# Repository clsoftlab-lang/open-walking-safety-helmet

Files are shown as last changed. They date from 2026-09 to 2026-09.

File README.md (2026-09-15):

# Open Walking Safety Helmet

**English** · [한국어](README.ko.md)

> ### *Until the day blind people everywhere can walk like anyone else.*
> 전 세계 시각장애인이 일반인처럼 다닐 수 있는 그날까지.

An open-source helmet that helps blind and low-vision people walk safely.
It feels **head-height obstacles**, finds **stairs and drop-offs**, warns about
**approaching bikes, cars and people**, **reads signs aloud**, recognises **friends' faces**
and sends an **SOS** with your location. It tells you through **vibration on your head** and
**voice**.

Everything is free: firmware, 3D-printable parts, wiring, phone app, documents, **and the
patent.**

**Inventor and project lead:** CLSOFTLAB (씨엘소프트랩), Dr. Lee Il-guk (이일국 박사)
**Patent:** Korean Patent No. 10-2560496, released royalty-free for everyone. See the [Patent Pledge](PATENT_PLEDGE.md).

> [!WARNING]
> **Status: v1.0 reference design, not yet field-validated.** It is an assistive aid, not a
> certified medical device. It **does not replace** a white cane, guide dog or orientation
> and mobility training. Read the [safety guide](docs/en/06-safety.md) before walking with it.

---

## Why a helmet and not glasses?

Sensors can miss things. If a collision happens anyway, **a helmet still protects the head.**
So this project never weakens the helmet:

- Start from a **certified bicycle helmet**. Never 3D-print the shell.
- **Never drill, cut or glue** into the helmet.
- Modules attach with **straps and removable pads** so they break away under impact.
- They sit flat on the shell (curved undersides), stick out at most 35–40 mm (30 mm for small modules) and have rounded edges.

## What it does

| You feel / hear | When |
|---|---|
| Forehead buzz that speeds up, then stays on | Something at **head height** ahead (branch, sign, truck mirror): 2 m → 1.2 m → 0.6 m |
| All three motors, two long buzzes + "Step down ahead" | **Stairs down, curb or platform edge** |
| Left or right side buzzes + "Bicycle approaching from the right" | A person, bike or car **moving towards you** |
| Two gentle buzzes on one side + "Mina is ahead on the left" | An **enrolled friend** is nearby |
| Press ○ | **Reads text** in front of you (signs, labels) |
| Press △ | **Describes the scene**: "2 people ahead, bicycle on the right" |
| Hold □ for 3 s, or fall down | **SOS** countdown, then the phone app shows your location with one-tap call and SMS |
| Three short forehead buzzes every 10 s | **Something is broken.** Don't trust silence. Distance sensors keep working. |

Full haptic language: [User guide](docs/en/05-user-guide.md)

## How it works

```
 Camera (wide) ─► object detection · tracking · time-to-contact ─┐
                  face recognition · text reading (on demand)    │
 LiDAR forward ─► head-height obstacle zones  (works without AI) ─┼─► priority arbiter ─► 3 vibration motors
 LiDAR down    ─► stairs / drop-off / step detector              │                    └► voice (open-ear headset)
 IMU           ─► fall detection                                 │                    └► phone app (BLE): location · SOS
 3 buttons ○△□ ─► read · describe · status / SOS ────────────────┘
 Watchdog: every sensor is monitored, and failures are announced
```

- **Runs offline** on a Raspberry Pi 5, CPU only. No GPU, no cloud.
- **The safety path doesn't depend on AI.** LiDAR warnings keep working if the camera or a neural network fails.
- **Faces never leave the helmet.**

Architecture and every number: [System design specification](docs/en/00-system-design-spec.md)

## Hardware at a glance

Raspberry Pi 5 · Camera Module 3 Wide · 2 × TF-Luna LiDAR · MPU-6050 IMU · 3 coin vibration
motors + ULN2003 · 3 tactile buttons · USB audio + open-ear headset · USB-C power bank in your
pocket · a certified bicycle helmet · 3D-printed PETG/TPU parts.

**No soldering** in the reference build. Every part is printable on a 220 × 220 mm printer.
See the [bill of materials](docs/en/01-bill-of-materials.md) for parts and cost ranges, and the **[buying guide](docs/en/10-buying-guide.md)** for verified purchase links and the most common buying mistakes.

## Repository

| Folder | What | Licence |
|---|---|---|
| [`firmware/`](firmware/) | Python firmware for the helmet (with a PC simulator) | Apache-2.0 |
| [`hardware/`](hardware/) | Parametric OpenSCAD sources, ready-to-print STL, renders, wiring diagram | CERN-OHL-P-2.0 |
| [`app/`](app/) | Phone companion web app (Web Bluetooth): location, SOS, settings | Apache-2.0 |
| [`docs/`](docs/) | Design spec, BOM, wiring, printing, assembly, user guide, safety, tests (English + 한국어) | CC BY 4.0 |
| [`1020210101227.pdf`](1020210101227.pdf) | Original patent publication (Korean) | Public record |

## Get started

**1. Try it on a PC (no hardware needed)**

```bash
cd firmware
pip install -e .[dev]
python -m owsh.tools.download_models
python -m owsh --sim --video path/to/walking_video.mp4
```

The simulator shows detections, the three motor bars and the simulated LiDARs. Keyboard shortcuts are in [firmware/README.md](firmware/README.md).

**2. Build a helmet:**
[Bill of materials](docs/en/01-bill-of-materials.md) → [Buying guide](docs/en/10-buying-guide.md) → [3D printing](docs/en/03-3d-printing-guide.md) → [Wiring](docs/en/02-wiring-guide.md) → [Assembly & setup](docs/en/04-assembly-guide.md) → [Test plan](docs/en/07-test-plan.md)

**3. Phone app:** open [`app/`](app/) on Android Chrome over HTTPS, or use the built-in demo helmet to try it out.

## The whole world is invited

This project only succeeds if it is tested and improved by the people who use it, everywhere.

- **Blind and low-vision walkers, O&M instructors:** field tests and honest feedback ([field test report](.github/ISSUE_TEMPLATE/field_test_report.yml))
- **Makers:** build one, improve the mounts, try cheaper parts
- **Translators:** voice prompts in your language. Safety phrases need review by a native blind speaker ([translation guide](docs/en/09-translation-guide.md))
- **ML engineers:** datasets and detectors for tactile paving, crossings, ramps, elevator buttons
- **Developers:** firmware, native Android/iOS app with automatic SOS, navigation

Start with [CONTRIBUTING.md](CONTRIBUTING.md). Roadmap: [Patent mapping and roadmap](docs/en/08-patent-and-roadmap.md).

## The story

Dr. Lee Il-guk filed this invention in 2021 so that blind people could walk safely, and it was
registered as a Korean patent in 2023. Building the whole system alone once seemed out of
reach. With today's AI tools, including Claude, it has become possible to design it, write
the software and publish everything. So he is giving it to the world for free.
CLSOFTLAB and Dr. Lee Il-guk will keep developing it.

## Contributors

- **CLSOFTLAB (씨엘소프트랩), Dr. Lee Il-guk** — inventor and project lead
- **LWJ** — high school student, Gyeonggi-do, Korea
- **LMJ** — middle school student, Gyeonggi-do, Korea
- Designed and built with Claude (Anthropic's AI)

## Licence

- Software: [Apache-2.0](LICENSES/Apache-2.0.txt)
- Hardware: [CERN-OHL-P-2.0](LICENSES/CERN-OHL-P-2.0.txt)
- Documentation: [CC BY 4.0](LICENSES/CC-BY-4.0.txt)
- Patent: [royalty-free pledge](PATENT_PLEDGE.md)

Details in [NOTICE](NOTICE). © 2026 CLSOFTLAB (씨엘소프트랩), Dr. Lee Il-guk (이일국)

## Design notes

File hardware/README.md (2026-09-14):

<!-- SPDX-License-Identifier: CERN-OHL-P-2.0 -->
<!-- Copyright 2026 CLSOFTLAB (씨엘소프트랩), Dr. Lee Il-guk (이일국) -->

# Open Walking Safety Helmet — printable hardware (v1.1, conformal)

Parametric OpenSCAD models, STL files, renders and wiring for the clip-on modules of the
Open Walking Safety Helmet (OWSH). The single source of truth is
[`docs/en/00-system-design-spec.md`](../docs/en/00-system-design-spec.md) (§1, §4, §10).

> [!CAUTION]
> **The helmet's protection comes first (spec P1/P2).**
> - Use a **certified** bicycle / multisport helmet (EN 1078, CPSC 1203, AS/NZS 2063, KC or equivalent).
> - **Never 3D-print the helmet shell. Never drill, cut, glue into or melt the shell or the EPS liner.**
> - Attach modules **only** with 20 mm hook-and-loop straps through existing vents and removable
>   3M Dual Lock pads, so they **detach under impact**. Do not replace straps with screws, zip ties or glue.
> - Keep every external module low and rounded. The modules sit directly on a thin saddle that follows
>   the shell — no stilts, no gaps that can catch a branch.
> - The helmet **assists, never replaces** the white cane or guide dog.
> - A modified helmet is no longer the certified product. Never sell one as certified without testing
>   by an accredited lab.

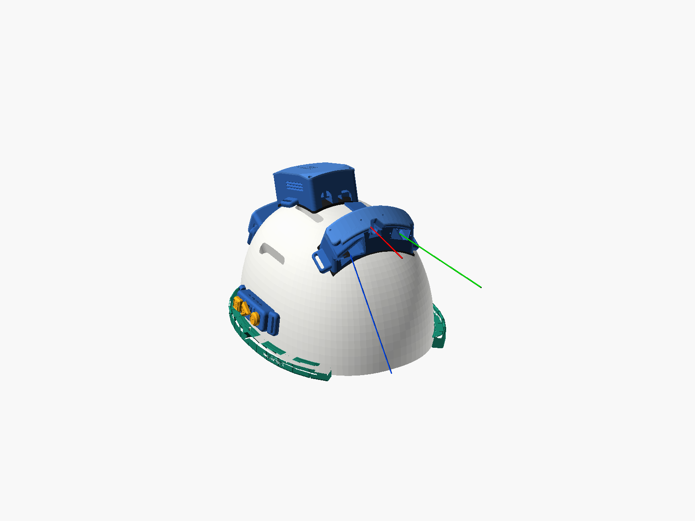
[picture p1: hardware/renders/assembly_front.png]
Assembly, front


| Rear | Side (orthographic; red camera 10° down, green forward LiDAR horizontal, blue down LiDAR 50°) |
|---|---|
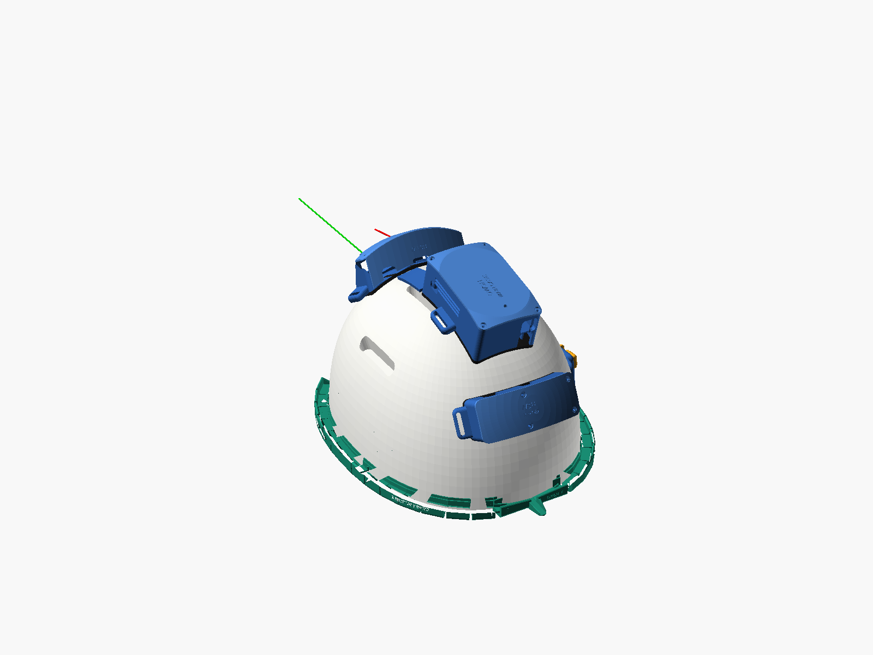
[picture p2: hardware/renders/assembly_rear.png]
Assembly, rear
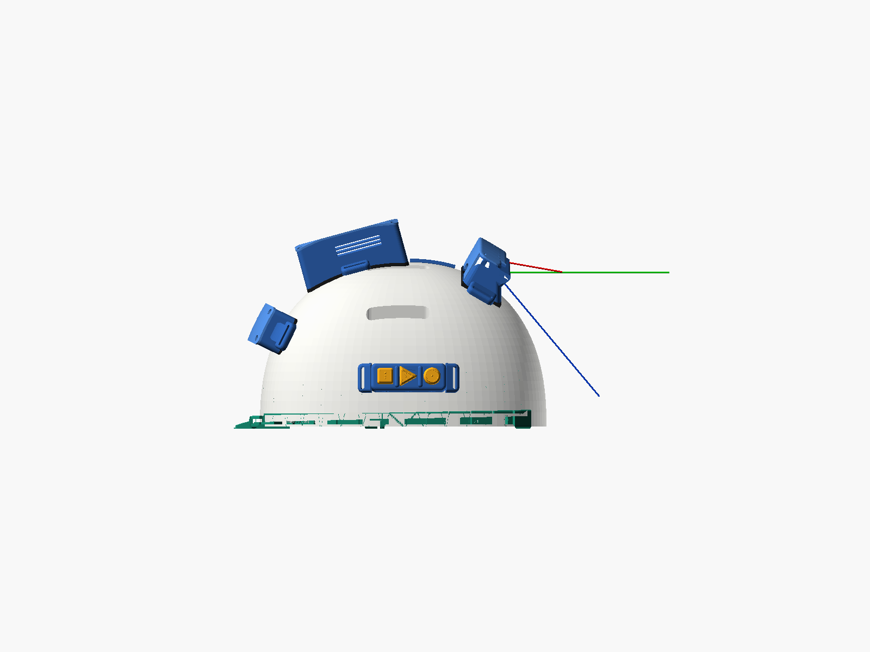
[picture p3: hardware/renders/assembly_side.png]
Assembly, side
|  |  |

## What changed in v1.1

- **Conformal modules.** The front pod, main case and new aux pod have undersides that follow the shell,
  so each sits on a **uniform 3 mm TPU saddle** (was: flat modules on saddles up to 34 mm thick at the corners).
- **Front pod** is a curved bar: the LiDAR bays on the flanks are rolled about their own beam axis
  (beam directions unchanged), the rain visor has a rounded camera-view notch, and the down-LiDAR facet
  is bevelled cleanly away from the camera's field of view.
- **Main case** turned front-to-back, shrunk to 99 × 63 mm, ribbed curved underside, lid capped by an
  offset of the shell. It now holds only the Pi 5 + Active Cooler, IMU and LED.
- **New aux pod** (`aux_pod_base`, `aux_pod_lid`) on the back of the head holds the ULN2003 board and the
  USB audio adapter. They could not fit inside a ~100 × 72 mm case under a 40 mm height cap: beside the
  Pi the shell drops 6–10 mm, which pushes any 15 mm-tall board over 40 mm. The aux pod is also
  closer to the headset jacks and balances the front pod. Extra part: a short (10–15 cm) USB-A
  extension from the Pi to the audio adapter.
- Assembly envelope = typical adult M/L helmet, 270 L × 210 W × 155 H mm. The measured gap between
  saddle and shell is ≤ 4 mm everywhere.

## Measured numbers (from the exported meshes)

| Module | Footprint (mm) | Max height above shell, incl. 3 mm saddle | Printed parts, est. mass* |
|---|---|---|---|
| Front pod (base + cover) | 107.6 across × 42 deep (132 incl. strap tabs) | **34.8 mm**, uniform | 34.6 cm³ → ≈ 40 g PETG |
| Main case (base + lid) | 99.1 along × 62.6 across (87.5 across incl. tabs) | **39.8 mm** (34.6 mm at the centre) | 45.9 cm³ → ≈ 52 g PETG |
| Aux pod (base + lid) | 98.6 × 37.6 (123 incl. tabs) | **23.4 mm**, uniform | 26.7 cm³ → ≈ 30 g PETG |
| Saddles (pod / case / aux) | as above, 3.0 mm thick | — | 13.6 / 19.1 / 11.5 cm³ → ≈ 13 / 18 / 11 g TPU |
| Button module + caps | 26 × 71 (96 incl. tabs) | 16.5 mm housing, ≈ 21 mm with caps | 18.9 cm³ → ≈ 22 g PETG |

\* Mass = STL volume × density (PETG 1.27 g/cm³, TPU 1.21 g/cm³) × 0.9 for PETG parts (2 mm walls are
almost solid at 4 perimeters) and × 0.8 for TPU at 3 walls / 15 % infill. Check your slicer.
Main case clearances echoed by the model: cooler → lid 1.2 mm, USB stacks 2.9 mm, header + Dupont 5.2 mm.

## Folder layout

```
hardware/
  openscad/lib/owsh_common.scad     shared parameters + helpers (rounded boxes, conformal offset surfaces,
                                    strap slots, louvres, screw bosses, cable gland slots, labels)
  openscad/lib/front_pod_lib.scad   front pod parameters, sensor layout, cross-section sweep geometry
  openscad/lib/main_case_lib.scad   main case parameters, Pi 5 layout, clearance checks
  openscad/lib/aux_pod_lib.scad     aux pod (ULN2003 + USB audio adapter)
  openscad/lib/rain_gutter_lib.scad rain flow channel (patent 112) + rear nozzle (patent 113)
  openscad/<part>.scad              one file per printable part, oriented for printing
                                    (-D worn=true exports the worn frame)
  openscad/assembly_preview.scad    all modules on the helmet envelope (not printed)
  stl/                              print-ready meshes;  stl/worn/  worn-frame meshes for the assembly
  renders/                          PNG previews + render_log.txt
  scripts/render_all.ps1 / .sh      re-export everything
  wiring/wiring_diagram.svg, pinout.md
```

## Printed parts

| File (STL) | Part | Material | Qty | Print orientation (as exported) | Supports | Infill | Est. mass |
|---|---|---|---|---|---|---|---|
| `front_pod_base` | Curved pod body: camera bay (10° down), forward LiDAR, down LiDAR facet (50°), strap tabs | PETG/ASA | 1 | worn way up | **yes, build plate only** (curved underside) | 4 walls, 25 % gyroid | 28 g |
| `front_pod_cover` | Curved top plate with rain visor + camera notch, rear wall with FPC / cable exits | PETG/ASA | 1 | top face down | yes, under the curved top | 4 walls, 25 % | 12 g |
| `main_case_base` | Pi 5 base: standoffs, IMU slot, ribbed curved underside, louvres, USB-C / USB-A openings | PETG/ASA | 1 | floor down | yes, under the ribs | 4 walls, 25 % | 40 g |
| `main_case_lid` | Lid capped by the shell offset, LED light-pipe hole, fan air pocket | PETG/ASA | 1 | top face down | yes, under the curved rim | 4 walls, 25 % | 13 g |
| `aux_pod_base` | ULN2003 cradle + USB audio adapter rails, headset-jack opening | PETG/ASA | 1 | floor down | yes, under the curved floor | 4 walls, 25 % | 22 g |
| `aux_pod_lid` | Curved lid | PETG/ASA | 1 | top face down | yes | 4 walls, 25 % | 9 g |
| `saddle_pad` | Three flat 3 mm TPU sheets with relief slits (pod, case, aux) — they bend onto the shell | TPU 95A | 3 (1 plate) | flat | none | 100 % or 3 walls/15 % | 41 g (all three) |
| `button_module` | Housing for 3 × 12 mm tactile switches, guard ridges, angled strap tabs | PETG | 1 | floor down | tiny, under the angled tabs | 4 walls, 25 % | 19 g |
| `button_caps` | ○ 1 dot · △ 2 dots · □ 3 dots, raised tactile edges | PETG | 1 set | socket side down | none | 100 % | 3 g |
| `haptic_pad` | Coin ERM pad with side slot and hook-tape recess | TPU 95A | 3 | skin membrane down | none | 3 walls, 15 % | 3 g each |
| `strap_anchor` | 20 mm strap buckle, slots 21 × 3.2 mm | PETG | 4 | flat | none | 4 walls, 25 % | 3 g each |
| `cable_clip` | 3 bundle clips + 3 FPC-cover clips | PETG | 6 | lying on the side | none | 100 % | 4 g (plate) |
| `fpc_cover` | Low flexible channel for the camera FPC, 150 mm | PETG | 1–2 | flat | none | 100 % | 7 g |
| `rain_gutter_segment` | Flow channel, front high → rear low, 3 rim clips per segment; plate R1 R2 L1 L2 | TPU 95A | 4 | upright | none | 3 walls, 15 % | 86 g (all four) |
| `rain_nozzle_rear` | Rear nozzle joining both sides, outlet backwards/downwards | TPU 95A | 1 | upright | none | 3 walls, 15 % | 9 g |

All strap slots are **21 × 3.2 mm** (20 mm hook-and-loop strap + clearance). All parts fit a 220 × 220 × 250 mm bed.

<table>
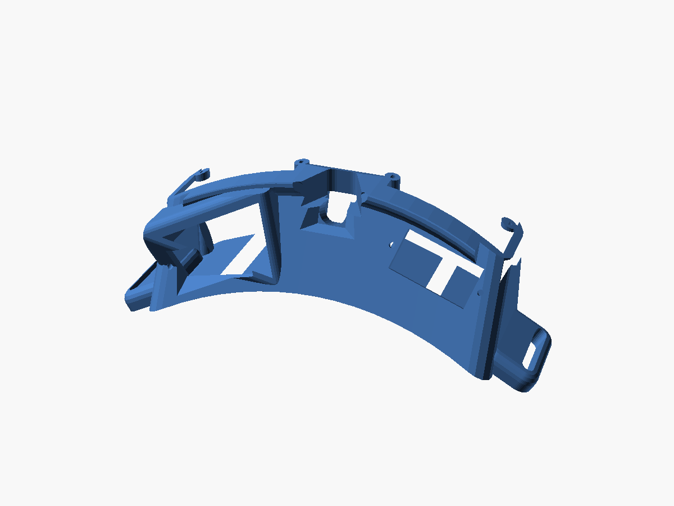
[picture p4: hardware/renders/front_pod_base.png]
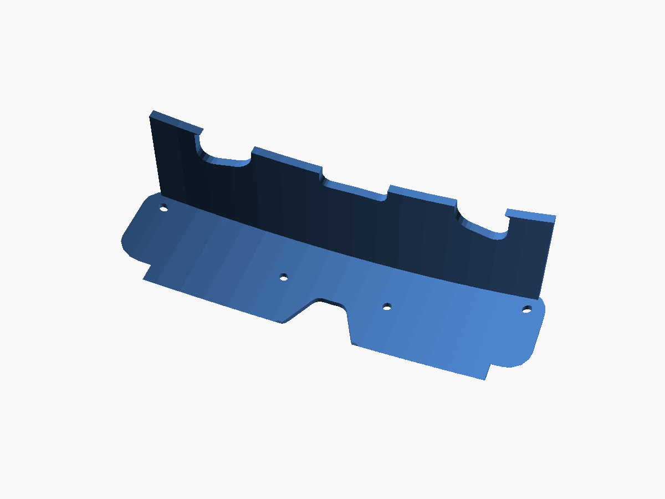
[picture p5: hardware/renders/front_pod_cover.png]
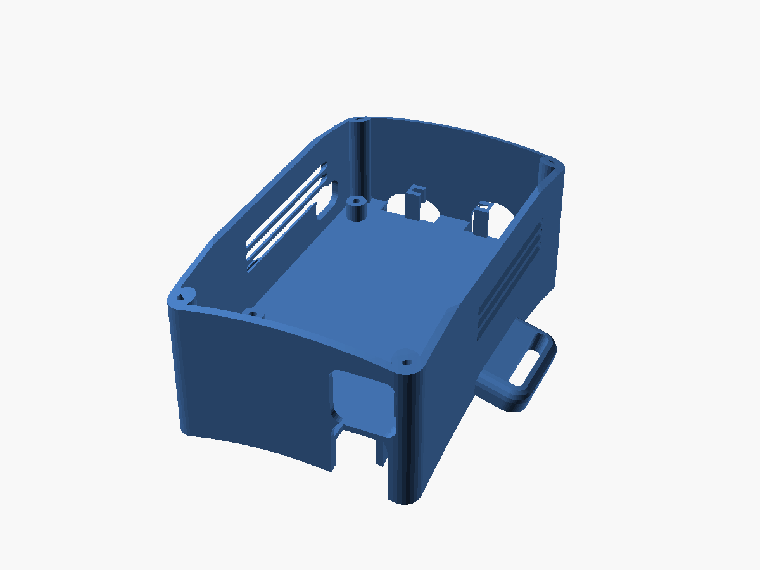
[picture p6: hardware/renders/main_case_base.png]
<tr><td><br>front_pod_base</td><td><br>front_pod_cover</td><td><br>main_case_base</td></tr>
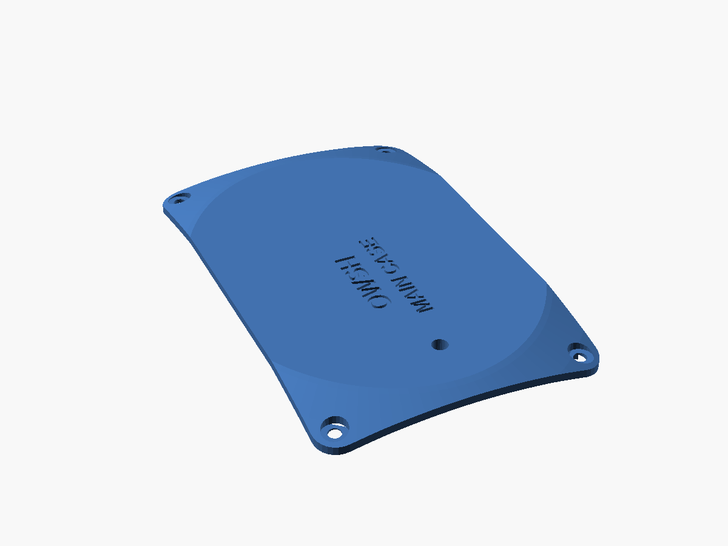
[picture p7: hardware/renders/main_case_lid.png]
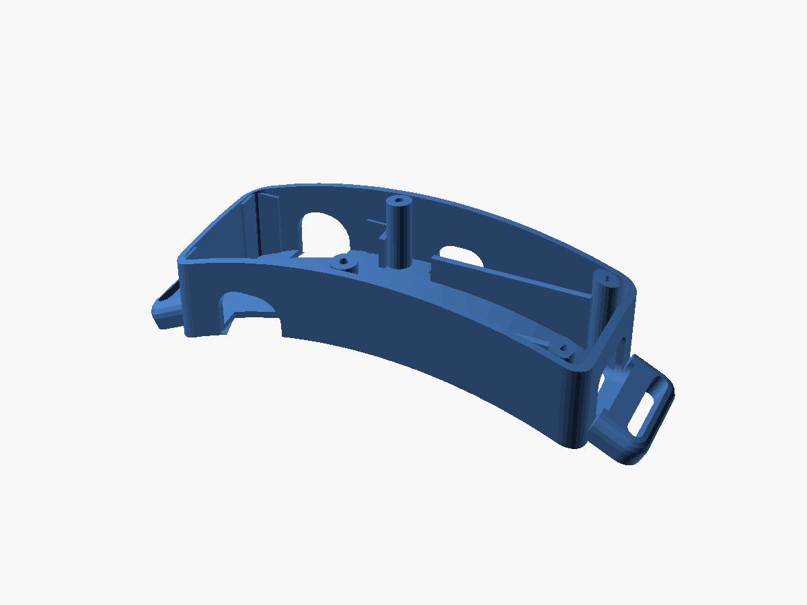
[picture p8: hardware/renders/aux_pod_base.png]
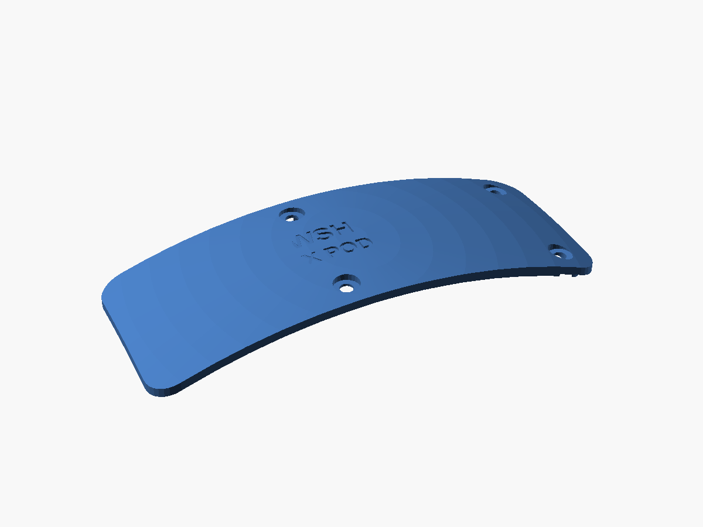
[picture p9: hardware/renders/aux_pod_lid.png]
<tr><td><br>main_case_lid</td><td><br>aux_pod_base</td><td><br>aux_pod_lid</td></tr>
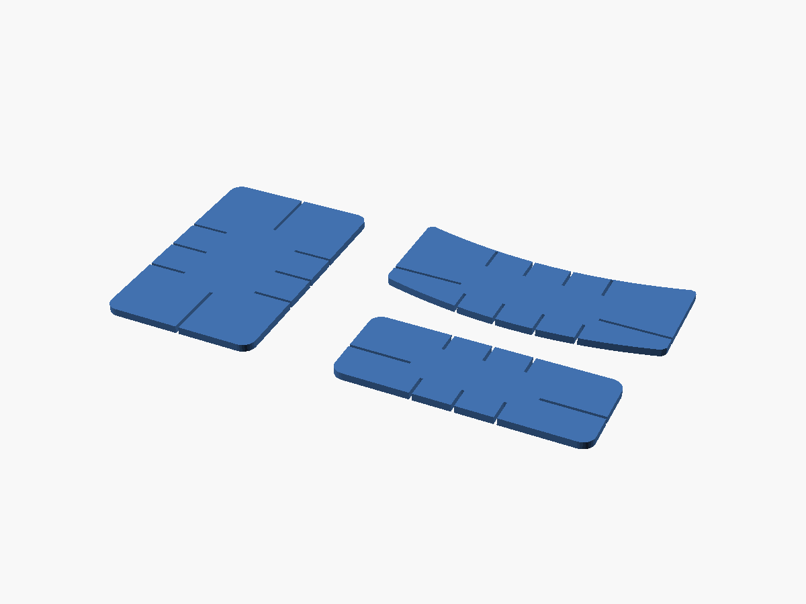
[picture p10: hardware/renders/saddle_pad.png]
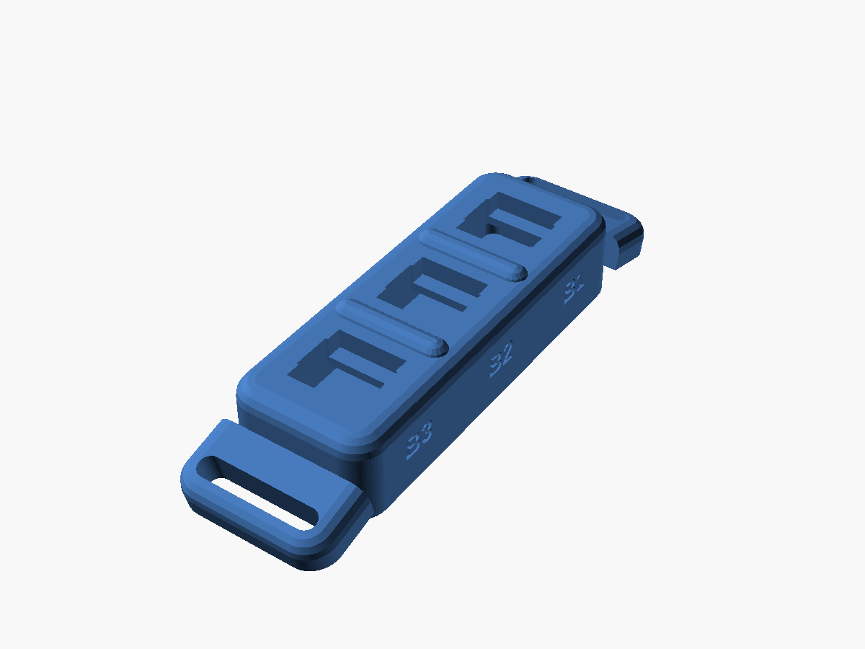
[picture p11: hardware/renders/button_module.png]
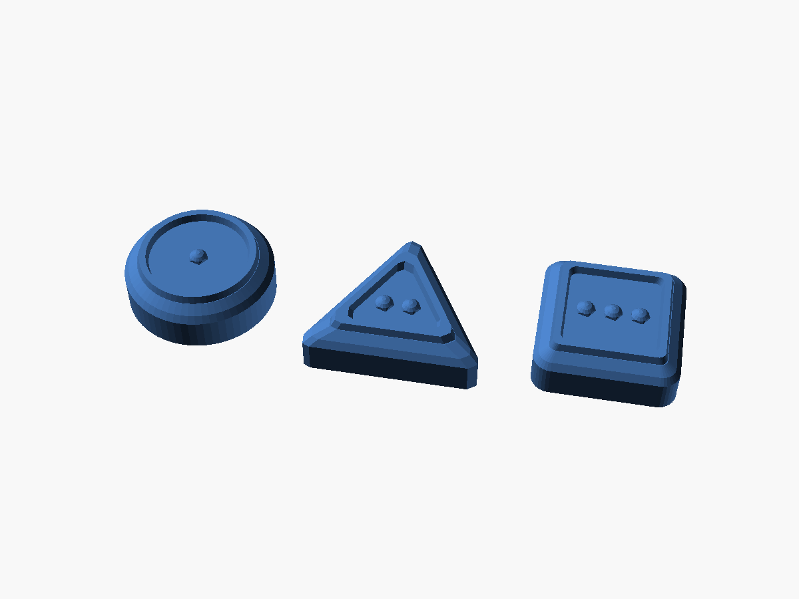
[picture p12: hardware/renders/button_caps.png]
<tr><td><br>saddle_pad</td><td><br>button_module</td><td><br>button_caps</td></tr>
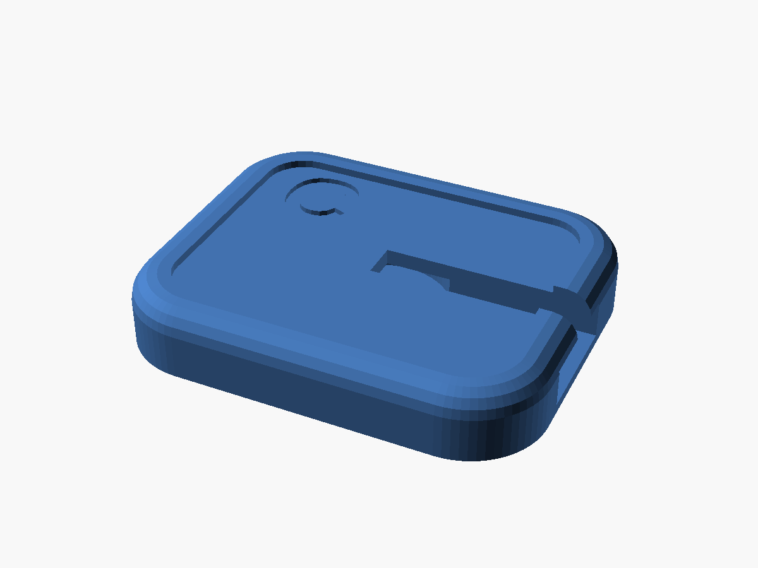
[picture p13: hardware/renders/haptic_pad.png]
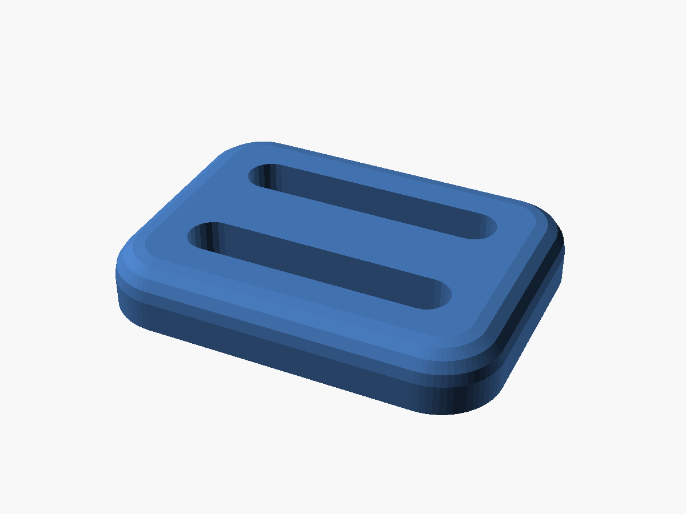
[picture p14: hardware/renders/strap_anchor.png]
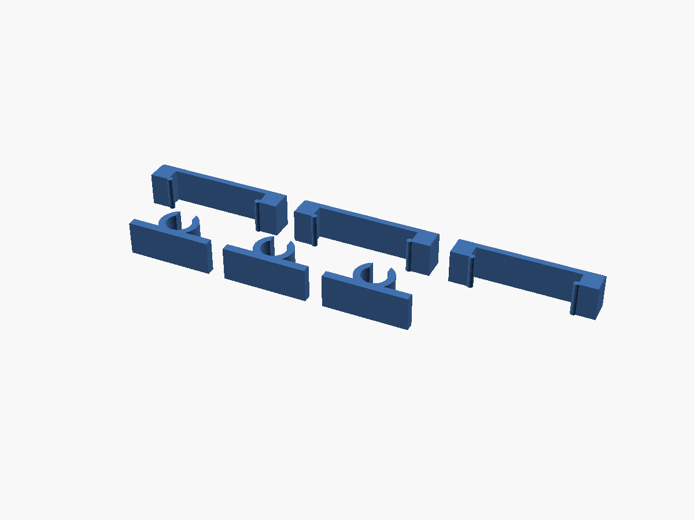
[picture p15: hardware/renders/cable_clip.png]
<tr><td><br>haptic_pad</td><td><br>strap_anchor</td><td><br>cable_clip</td></tr>
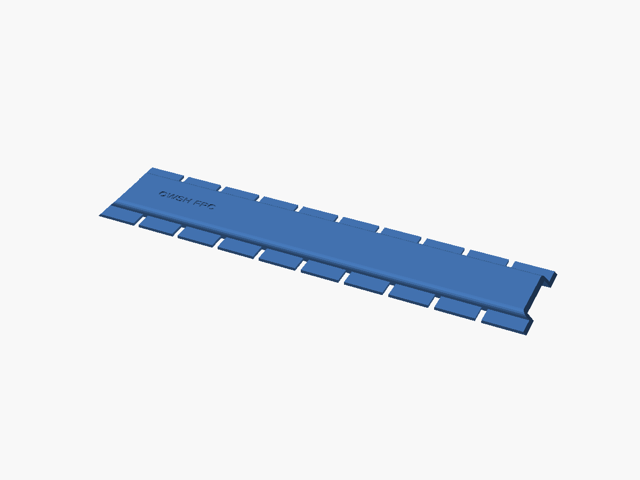
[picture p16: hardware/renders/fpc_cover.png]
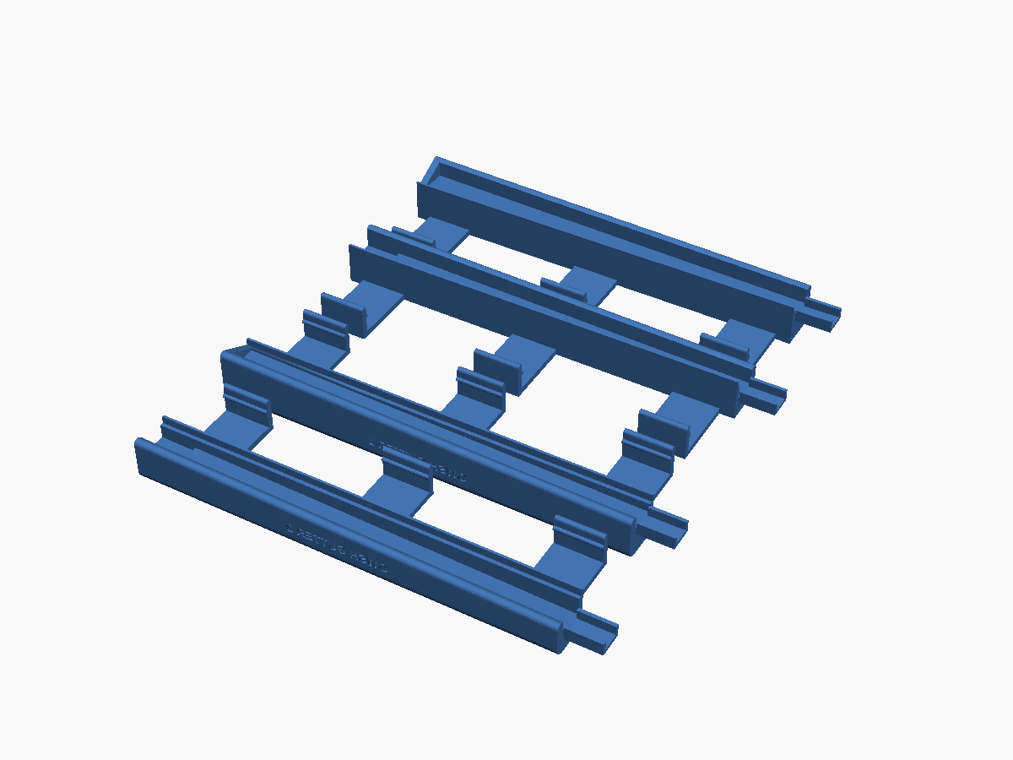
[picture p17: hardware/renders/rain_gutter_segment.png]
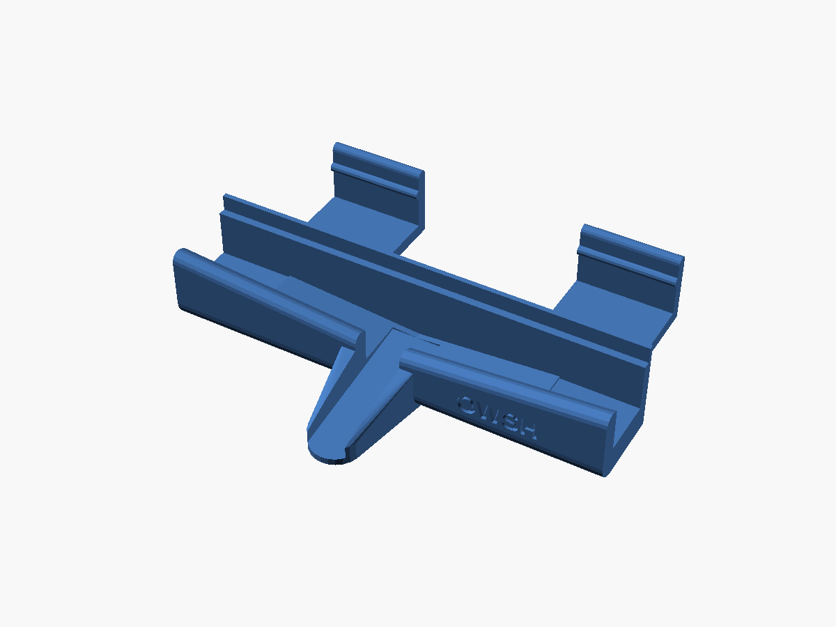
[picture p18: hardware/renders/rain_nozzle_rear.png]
<tr><td><br>fpc_cover</td><td><br>rain_gutter_segment</td><td><br>rain_nozzle_rear</td></tr>
</table>

## Print settings (spec §10)

- 0.2 mm layers, 4 walls, 25 % gyroid infill for rigid parts; **PETG 240 °C / bed 80 °C** (or ASA).
  Do not use PLA: it softens in summer sun and in hot cars.
- The curved undersides and curved lids need **supports from the build plate only** (tree/organic
  supports recommended; they touch only the side that faces the saddle or the shell offset).
- TPU 95A: 3 walls, 15 % infill (saddles: 100 %), slow (20–25 mm/s), no or very short retraction.
- Test your fit first: print `button_caps` and one `strap_anchor`. If parts are too tight, raise `clr`.

## Assembly hardware and post-processing

| Where | Fastener | Self-tapping (default) | Heat-set inserts (optional) |
|---|---|---|---|
| Pi 5 → case standoffs | 4 × M2.5 × 6 | pilot 2.2 mm | M2.5 × 4 insert, hole 3.6 mm |
| Lid → main case, lid → aux pod | 4 × M2.5 × 8 pan head each | pilot 2.2 mm | hole 3.6 mm |
| Camera → pod | 4 × M2 × 5 | pilot 1.8 mm | M2 × 3 insert, hole 3.2 mm |
| TF-Luna → pod | 2 × M2 × 5 each | pilot 1.8 mm | hole 3.2 mm |
| Cover → pod | 4 × M2 × 8 | pilot 1.8 mm | hole 3.2 mm |

1. Remove supports and any elephant foot from the strap slots so the strap slides freely.
2. Self-tapping: drive each screw in once, back it out, then assemble. Do not over-torque PETG.
3. Heat-set inserts: set `use_heat_set = true` in `lib/owsh_common.scad`, re-export, press inserts at ~230 °C.
4. Press the 3 mm LED into the main case lid from inside.
5. Coin motors slide into the haptic pads from the side; stick hook tape into the recess (never glue to EPS).
6. Saddles: Dual Lock on both faces (or hook-and-loop). The saddle only rests on the shell.
7. Straps: down through a strap tab slot, through a helmet vent, back up. Snug, not tight.
8. Aux pod: plug the USB audio adapter onto a 10–15 cm USB-A extension from the Pi's USB 2.0 port
   (rear opening of the main case); the ULN2003 gets GPIO17/27/22 + 5 V + GND from the header, and the
   motor leads leave through the lower notch toward the comfort pads.
9. Gutter: push the rim into the clips, slide segment 2 over segment 1's spout, and both rear spouts into the nozzle.

## Customising

Everything is a named parameter at the top of the library files (uncertain values are marked "verify").
Edit the file or override on the command line, e.g.
`openscad -D mount_pitch_deg=22 -D pod_R=120 -o stl/front_pod_base.stl openscad/front_pod_base.scad`.

| Parameter | File | Default | What to do |
|---|---|---|---|
| `pod_R` | `lib/front_pod_lib.scad` | 110 mm | Shell radius across the head under the pod. |
| `case_R_lat`, `case_R_long` | `lib/main_case_lib.scad` | 110 / 140 mm | Shell radii across / along the head under the main case. |
| `aux_R_lat`, `aux_R_long` | `lib/aux_pod_lib.scad` | 110 / 140 mm | Shell radii at the back of the head. |
| `saddle_t` | `lib/owsh_common.scad` | 3 mm | Saddle thickness (keep ≤ 4 mm). |
| `mount_pitch_deg` | `lib/front_pod_lib.scad` | 30° | Slope of the shell under the pod (phone inclinometer, head level). Sensor angles are compensated. |
| `case_max_h` | `lib/main_case_lib.scad` | 39.6 mm | Height cap of the main case above the shell. |
| `clr` | `lib/owsh_common.scad` | 0.3 mm | Fit clearance per side. |
| `use_heat_set` | `lib/owsh_common.scad` | false | Self-tapping pilots vs. insert holes. |
| `rim_t`, `seg_len`, `slope_deg`, `clip_count` | `lib/rain_gutter_lib.scad` | 22, 140, 1.2°, 3 | Rim thickness, segment length, channel slope. |
| `stem_shape`, `stem_d` | `button_caps.scad` | round, 7.0 mm | Match your tactile switches. |
| `side_R` | `button_module.scad` | 140 mm | Shell radius along the button module (angles its strap tabs). |

**How to measure a shell radius:** place a straight edge of length L across the shell, measure the gap h in
the middle; R ≈ L² / (8 h). For example, L = 100 mm and h = 11 mm gives R ≈ 114 mm.

Check these with calipers before printing: camera lens barrel and height (`cam_*`), TF-Luna holes and window
(`tfl_*`), Pi 5 cooler footprint (`pi_cooler_rect`), USB stack height, header + Dupont height, GY-521
thickness (`imu_slot_w`), ULN2003 board and audio adapter size, switch actuator Ø, coin motor Ø, rim thickness.

## Re-rendering

Requires OpenSCAD 2021.01 or newer (tested with 2021.01 / CGAL).

```powershell
powershell -ExecutionPolicy Bypass -File hardware\scripts\render_all.ps1            # everything
powershell -ExecutionPolicy Bypass -File hardware\scripts\render_all.ps1 -Parts saddle_pad,assembly_preview
```
```bash
hardware/scripts/render_all.sh                    # everything (OPENSCAD=/path/to/openscad to override)
hardware/scripts/render_all.sh front_pod_base     # one part
```

The scripts write `stl/<part>.stl`, `renders/<part>.png`, the worn-frame meshes in `stl/worn/`, three
assembly views and `renders/render_log.txt`. Measured on OpenSCAD 2021.01: parts 9 min total
(slowest: `main_case_lid` 80 s, `aux_pod_base` / `aux_pod_lid` 75 s, `front_pod_base` 65 s),
worn exports 7.3 min, assembly views 12–22 s each — about 17 min for a full run.

## Known limitations / still out of the original spec

- **Height vs. spec P2 (≤ 30 mm):** front pod 34.8 mm and main case 39.8 mm (the Pi 5 + Active Cooler
  alone needs ~31.5 mm). The aux pod (23.4 mm) and button module (≈ 21 mm) are within 30 mm.
- **Rain gutter mass:** four segments ≈ 86 g + nozzle ≈ 9 g TPU, above the 60 g budget. Shorter or
  fewer segments, or the gutter left off, bring it down.
- **Total added mass** without the gutter is ≈ 330 g (printed parts ≈ 190 g incl. saddles + electronics),
  within the 380 g budget. With the gutter it is ≈ 425 g.
- **Supports:** the conformal parts need build-plate supports on their curved faces (v1.0 parts did not).
- **Cooler clearance** under the main case lid is 1.2 mm plus a 0.8 mm pocket; watch `cpu_temp_c` in hot weather.
- The front pod's curvature radius is fixed per print (`pod_R`); a very different shell radius can leave
  gaps under the pod's ends. Measure first.

## Wiring

See [`wiring/wiring_diagram.svg`](wiring/wiring_diagram.svg) and [`wiring/pinout.md`](wiring/pinout.md).
Pin assignments are unchanged in v1.1; only the ULN2003 and USB audio adapter moved to the aux pod.

## License

CERN-OHL-P-2.0 — see [`LICENSE`](LICENSE). Copyright 2026 CLSOFTLAB (씨엘소프트랩), Dr. Lee Il-guk (이일국).

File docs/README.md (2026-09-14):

# Documentation · 문서

> Part of the Open Walking Safety Helmet · Licensed CC BY 4.0 · © 2026 CLSOFTLAB, Dr. Lee Il-guk

*Until the day blind people everywhere can walk like anyone else.*
전 세계 시각장애인이 일반인처럼 다닐 수 있는 그날까지.

The system design specification is the single source of truth. When a guide and the spec disagree, the spec
wins. Please open an issue.

설계서가 유일한 기준 문서입니다. 가이드와 설계서가 다르면 설계서를 따르고, 이슈로 알려 주십시오.

## Where to start · 어디서 시작할까요

- **I want to use the helmet** (users, families, O&M instructors):
  [User guide](en/05-user-guide.md) → [Safety](en/06-safety.md)
- **헬멧을 사용하려고 합니다** (사용자, 가족, 보행지도사):
  [사용자 가이드](ko/05-사용자가이드.md) → [안전 수칙](ko/06-안전수칙.md)
- **I want to build one:**
  [Bill of materials](en/01-bill-of-materials.md) → [Buying guide](en/10-buying-guide.md) → [3D printing](en/03-3d-printing-guide.md) →
  [Wiring](en/02-wiring-guide.md) → [Assembly](en/04-assembly-guide.md) → [Test plan](en/07-test-plan.md)
- **직접 만들려고 합니다:**
  [부품 목록](ko/01-부품목록.md) → [구매 가이드](ko/10-구매가이드.md) → [3D 프린팅](ko/03-3D프린팅가이드.md) →
  [배선](ko/02-배선가이드.md) → [조립](ko/04-조립가이드.md) → [시험 계획](ko/07-시험계획.md)
- **I want to contribute:** [CONTRIBUTING.md](../CONTRIBUTING.md) · [Roadmap](en/08-patent-and-roadmap.md) ·
  [Translation guide](en/09-translation-guide.md)

## All documents · 전체 문서

| # | English | 한국어 | For |
|---|---|---|---|
| 00 | [System design specification](en/00-system-design-spec.md) | [시스템 설계서](ko/00-시스템설계서.md) | Everyone building or changing anything |
| 01 | [Bill of materials](en/01-bill-of-materials.md) · [bom.csv](bom.csv) | [부품 목록](ko/01-부품목록.md) | Builders |
| 02 | [Wiring guide](en/02-wiring-guide.md) | [배선 가이드](ko/02-배선가이드.md) | Builders |
| 03 | [3D printing guide](en/03-3d-printing-guide.md) | [3D 프린팅 가이드](ko/03-3D프린팅가이드.md) | Builders |
| 04 | [Assembly guide](en/04-assembly-guide.md) | [조립 가이드](ko/04-조립가이드.md) | Builders |
| 05 | [User guide](en/05-user-guide.md) | [사용자 가이드](ko/05-사용자가이드.md) | Users, families, O&M instructors |
| 06 | [Safety](en/06-safety.md) | [안전 수칙](ko/06-안전수칙.md) | Everyone |
| 07 | [Test plan](en/07-test-plan.md) | [시험 계획](ko/07-시험계획.md) | Builders, testers, O&M instructors |
| 08 | [Patent mapping and roadmap](en/08-patent-and-roadmap.md) | [특허 대응표와 로드맵](ko/08-특허와로드맵.md) | Contributors |
| 09 | [Translation guide](en/09-translation-guide.md) | [번역 가이드](ko/09-번역가이드.md) | Translators, reviewers |
| 10 | [Buying guide (verified links)](en/10-buying-guide.md) | [구매 가이드 (실제 구매 링크)](ko/10-구매가이드.md) | Builders |

## Same list, without a table · 표 없이 같은 목록

English:

- [00 System design specification](en/00-system-design-spec.md)
- [01 Bill of materials](en/01-bill-of-materials.md), with [bom.csv](bom.csv)
- [02 Wiring guide](en/02-wiring-guide.md)
- [03 3D printing guide](en/03-3d-printing-guide.md)
- [04 Assembly guide](en/04-assembly-guide.md)
- [05 User guide](en/05-user-guide.md)
- [06 Safety](en/06-safety.md)
- [07 Test plan](en/07-test-plan.md)
- [08 Patent mapping and roadmap](en/08-patent-and-roadmap.md)
- [09 Translation guide](en/09-translation-guide.md)
- [10 Buying guide](en/10-buying-guide.md)

한국어:

- [00 시스템 설계서](ko/00-시스템설계서.md)
- [01 부품 목록](ko/01-부품목록.md)
- [02 배선 가이드](ko/02-배선가이드.md)
- [03 3D 프린팅 가이드](ko/03-3D프린팅가이드.md)
- [04 조립 가이드](ko/04-조립가이드.md)
- [05 사용자 가이드](ko/05-사용자가이드.md)
- [06 안전 수칙](ko/06-안전수칙.md)
- [07 시험 계획](ko/07-시험계획.md)
- [08 특허 대응표와 로드맵](ko/08-특허와로드맵.md)
- [09 번역 가이드](ko/09-번역가이드.md)
- [10 구매 가이드](ko/10-구매가이드.md)

## Project files · 프로젝트 파일

- [Project README](../README.md) · [한국어 README](../README.ko.md)
- [Patent pledge · 특허 무상 실시 선언](../PATENT_PLEDGE.md)
- [Contributing](../CONTRIBUTING.md) · [Code of conduct](../CODE_OF_CONDUCT.md) ·
  [Governance](../GOVERNANCE.md) · [Security](../SECURITY.md)
- [Licence notice](../NOTICE)

## Other languages · 다른 언어

Documentation in other languages is welcome under `docs/<lang>/`. See the [translation guide](en/09-translation-guide.md).

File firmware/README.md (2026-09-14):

# OWSH firmware

Firmware for the **Open Walking Safety Helmet**. It warns blind and low-vision walkers about
head-height obstacles, drop-offs and approaching objects. It can also read text, recognise enrolled
faces and send an SOS through a phone.

> **The helmet assists and never replaces the white cane or guide dog.**
> The authoritative design is [`../docs/en/00-system-design-spec.md`](../docs/en/00-system-design-spec.md).
> This firmware implements spec v1.0.

Licence: Apache-2.0 · Author: CLSOFTLAB, Dr. Lee Il-guk

---

## Quick start on a PC (simulator)

Requires Python ≥ 3.11 and a webcam or a video file.

```bash
cd firmware
python -m venv .venv && . .venv/bin/activate      # Windows: .venv\Scripts\activate
pip install -e ".[dev]"
python -m owsh.tools.download_models              # NanoDet, YuNet, SFace -> models/
python -m owsh --sim                              # webcam 0 + dashboard window
python -m owsh --sim --video path/to/walk.mp4     # a video instead of the webcam
python -m owsh --sim --lang ko                    # Korean voice
```

In `--sim` mode the LiDARs and the IMU are simulated and controlled from the dashboard. The
motors are drawn as bars and the buttons are keys. Speech uses `pyttsx3`, or `--tts print` to
print the text instead.

Headless runs are useful for CI or for checking detection on a recording:

```bash
curl -L -o samples/vtest.avi https://github.com/opencv/opencv/raw/4.x/samples/data/vtest.avi
python -m owsh --sim --video samples/vtest.avi --no-window --frames 300 --tts print \
       --save-frames samples/out --save-every 100
python -m owsh.tools.bench --video samples/vtest.avi       # detector FPS
```

### Keyboard map (dashboard window)

| Key | Action |
|---|---|
| `1` / `2` / `3` | short press B1 ○ / B2 △ / B3 □ |
| `Shift+1..3` or `q` / `w` / `e` | long press (B3 long = hold 3 s = SOS countdown) |
| `a` / `s` / `d` | double press |
| trackbars `forward cm`, `down cm` | simulated LiDAR distances (0 = no return) |
| `f` | simulate a fall |
| `l` / `k` | unplug / replug forward / down LiDAR (fault injection) |
| `c` | cover / uncover the camera (black frames → `camera_blocked`) |
| `z` | hold B1 + B3 for 5 s → safe shutdown (in simulation the power-off is only logged) |
| `v` / `t` | toggle simulated Pi under-voltage / overheating (85 °C) |
| `Esc` or `x` | quit |

What the buttons do (spec §7.2):

| Button | Short (< 0.8 s) | Long (≥ 1.5 s) | Double (< 0.4 s gap) |
|---|---|---|---|
| B1 ○ | read text (OCR) | repeat last message | — |
| B2 △ | describe scene | where am I (phone location) | who is here (faces) |
| B3 □ | status report | hold 3 s: SOS countdown | toggle voice mute (P3–P4) |

Every press vibrates `tick`. Any button cancels a running SOS countdown.

**Safe shutdown: hold B1 ○ and B3 □ together for 5 seconds.** The helmet says "Shutting down",
vibrates the start-up pattern in reverse (right → centre → left) and powers off 3 s later. As soon
as both buttons are down, their normal long presses are blocked, so this can never start an SOS.
Press both within about 1 s of each other (B1 alone held 1.5 s would already repeat the last
message). Letting go of either button before 5 s cancels the shutdown without doing anything else.

### Power warnings (Raspberry Pi)

Every 5 s the firmware reads the Pi's `get_throttled` flags and the CPU temperature:

- under-voltage for 10 s or longer → "Power is low. Charge the battery soon." (P2), repeated at
  most every 5 minutes while it lasts;
- CPU at 80 °C or hotter → "Helmet is overheating." (P2), repeated at most every 5 minutes, re-armed
  once the CPU cools below 75 °C.

The phone's `status` message carries `undervoltage` and `throttled` (current state, omitted when
unknown).

## On the Raspberry Pi 5

Use Raspberry Pi OS Bookworm 64-bit with the hardware wired per spec §4.2.

```bash
git clone <this repository> && cd <repo>/firmware
bash scripts/setup_pi.sh            # apt packages, I2C, venv, pip install -e .[pi,ble], models, systemd
sudo reboot
i2cdetect -y 1                      # expect 0x10 (TF-Luna) and 0x68 (MPU-6050)
.venv/bin/python -m owsh.tools.tfluna_addr --from 0x10 --to 0x11   # once, only the DOWN sensor connected
sudo systemctl start owsh && journalctl -u owsh -f
```

The service restarts automatically (`Restart=always`, `RestartSec=2`). Optional parts degrade
gracefully. A missing LiDAR, IMU, camera, GPIO, audio backend or Bluetooth stack produces a
spoken and vibrated **FAULT**, never a crash. Silence must never mean "safe".

### Pairing the phone (Bluetooth security)

The helmet only takes commands from a **paired (bonded) phone**, and the link is encrypted.
Otherwise anyone nearby could mute it or lower the drop-off sensitivity.

1. Switch the helmet on. While no phone is paired yet, pairing is always open. Once a phone is
   paired, pairing is open only for the first **2 minutes after each start**, so to add or replace
   a phone, restart the helmet (or hold B1 + B3 for 5 s and switch it on again).
2. In the phone app tap "Connect" and choose `OWSH-XXXX`.
3. When the app first sends a command, Android shows its normal system dialog, **"Pair with
   OWSH-XXXX?"**, with *Pair* and *Cancel* buttons. There is no PIN, because the helmet has no
   screen or keypad. Tap *Pair*. The phone stores the pairing, so later connections are automatic.
   iOS shows a similar "Bluetooth Pairing Request" alert. A screen reader reads the dialog aloud.
4. The helmet announces **"New phone paired: <phone name>."** If you hear this and did not pair
   a phone yourself, remove the pairing (see below) and restart the helmet.

On the Pi, `scripts/setup_pi.sh` installs `bluez-tools` and runs `bt-agent` with the
NoInputNoOutput capability (`owsh-bt-agent.service`). This agent accepts the Just Works pairing,
and the firmware decides when BlueZ is pairable. To remove all pairings, run
`bluetoothctl devices Paired`, then `bluetoothctl remove <address>`.

Settings the phone sends that reduce safety are always announced on the helmet: "Voice info
muted by phone", "Drop-off sensitivity set to low by phone", and "Volume set to N percent by
phone" (below 30 %). The phone's "say" messages are capped at P2 and limited to one every 3 s.
Configuration keys: `ble.security` (`encrypt`), `ble.bonded_only` (`true`),
`ble.pairing_window_s` (120), `ble.say_min_interval_s` (3), `ble.confirm_volume_below` (30).

Other tools:

```bash
python -m owsh.tools.enroll_face --name "Mina" --tag friend --camera 0   # or --images a.jpg b.jpg
python -m owsh.tools.enroll_face --list
pip install -e ".[ocr]"                                                   # optional text reading
```

Face photos stay in `data/faces/` on the helmet. Only names are ever sent to the phone.

## Architecture

```
reflex thread 50 Hz  TF-Luna fwd/down ─► zones (§5.1) / drop-off (§5.2) ─┐
imu thread 100 Hz    MPU-6050 ─► fall detector (§5.6) ───────────────────┤
vision thread        camera ─► blocked check ─► CLAHE ─► NanoDet ─► IoU  │
                     tracker ─► TTC ─► approach policy (§5.3) ───────────┤  EventBus (sync)
faces thread ≤ 2 Hz  YuNet + SFace (§5.4) ───────────────────────────────┤      │
buttons              gesture state machine (§7.2) ───────────────────────┤      ▼
ble thread           NUS GATT server (§8) ◄──────────────────────────────┴─ Arbiter + SOS + Controller
watchdog 10 Hz       heartbeats ─► FAULT events; drives arbiter/SOS timers      │        │
                                                              haptics mixer 10 ms   speech queue
```

| Module | Role |
|---|---|
| `owsh/config.py`, `config/default.yaml` | every threshold from the spec, validated |
| `owsh/events.py`, `owsh/bus.py` | event types, `Level` P0–P4, synchronous thread-safe bus |
| `owsh/arbiter.py` | hazard → haptic pattern, speech and phone alert; cooldowns; SOS state machine |
| `owsh/sensors/reflex.py` | median filter, zones with hysteresis, auto-calibrated drop-off detector |
| `owsh/sensors/tfluna.py`, `imu.py` | I2C drivers (smbus2), simulators, fall detector |
| `owsh/sensors/power.py` | under-voltage / throttling / temperature warnings, safe power-off |
| `owsh/vision/*` | camera sources, CLAHE, NanoDet decoding, tracker + TTC, describe, faces, OCR |
| `owsh/output/haptics.py` | spec §6.2 patterns, max-per-motor mixer, `max_duty` cap in the backend |
| `owsh/output/audio.py` | preemptive speech queue; piper / espeak-ng / pyttsx3 / print |
| `owsh/input/buttons.py` | debounced short / long / double state machine; gpiozero or keyboard |
| `owsh/link/protocol.py`, `ble.py` | pure JSON framing and chunking; `bless` NUS server or no-op link |
| `owsh/watchdog.py` | heartbeats, explicit faults, camera-blocked detector |
| `owsh/sim/dashboard.py` | desktop debug window |

Design rules the code follows:

- The **reflex path** (LiDAR → arbiter → motors) imports no vision code. It keeps working when the
  camera or the neural networks fail (P5).
- All timing uses an injectable monotonic clock, so the state machines are unit-tested with fake time.
- Logs are single lines with wall time and `mono=` monotonic time. `reflex zone=… sample_ts=…` and
  `haptic_on … latency_ms=…` measure the LiDAR → motor latency (spec T2, target ≤ 60 ms).

## Tests

```bash
python -m pytest -q
python -m compileall owsh
```

The tests cover config and spec values, i18n key and placeholder parity (en/ko), zones and hysteresis,
drop-off calibration, drop and step detection, tracker and TTC, the approach policy, haptic
patterns, the mixer and `max_duty`, the speech-queue rules, the button state machine, the fall
detector, protocol chunking round-trips, the watchdog and camera-blocked detection, the arbiter and
SOS flows, and a sim integration test (reflex latency, SOS, fault injection, dashboard). Detector
tests on `vtest.avi` run when the model and sample are present.

## Languages

Phrases live in `owsh/i18n/<lang>.json`. `en` and `ko` are maintained by the core team. A new
language must contain exactly the same keys and `{placeholders}`, which the tests check. A language
counts as verified only after review by a blind native speaker or an O&M instructor. Unverified
languages play a notice at boot.

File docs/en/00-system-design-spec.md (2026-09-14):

# Open Walking Safety Helmet — System Design Specification (v1.0)

> **Status:** Reference design v1.0 · **This document is the single source of truth.**
> Firmware, 3D models, the phone app and all guides MUST follow the pin map, dimensions,
> haptic language and protocol defined here. Change this file first, then the implementations.

- Patent: KR 10-2560496 "Walking safety helmet capable of recognizing surroundings"
  (application 10-2021-0101227, filed 2021-08-02, registered 2023-07-24)
- Patent holder / inventor / project lead: **CLSOFTLAB (씨엘소프트랩), Dr. Lee Il-guk (이일국 박사)**
- The patent holder releases this design free of charge for everyone. See `PATENT_PLEDGE.md`.
- Motto: *Until the day blind people everywhere can walk like anyone else.*
  (전 세계 시각장애인이 일반인처럼 다닐 수 있는 그날까지)

### Global project rules
- Default language of code, specs and issues: **English**. Every user-facing guide also in **Korean**.
- Voice/UI strings: `en` and `ko` are maintained by the core team. Additional languages
  (`es`, `fr`, `pt`, `ar`, `hi`, `zh-CN`, `ja`, `sw`, …) are welcome but a language is only marked
  **"verified"** after review by a native speaker who is blind or an O&M instructor — safety phrases
  must be unambiguous. Unverified languages are shipped with a first-boot notice.
- Emergency numbers are per-country settings, never hard-coded to one country.
- Units: metric by default, imperial selectable for voice.

---

## 1. Mission and design principles

**Mission:** let blind and low-vision people anywhere in the world walk as freely and safely
as sighted people, using parts anyone can buy and print.

**Why a helmet and not glasses:** a helmet protects the head if a collision or fall happens
anyway. The helmet's protective function is therefore **non-negotiable**:

| # | Principle | Consequence |
|---|---|---|
| P1 | **Never degrade impact protection** | Use a certified bicycle/multisport helmet (EN 1078, CPSC 1203, AS/NZS 2063, KC or equivalent). Never 3D-print the shell. Never drill, cut, glue into or melt the EPS liner or the shell. |
| P2 | **Breakaway, low-profile add-ons** | External modules attach with hook-and-loop straps through vents and/or removable adhesive pads so they detach under impact. Max height above the shell: **35 mm for the front pod, 40 mm for the main case** (a Pi 5 with Active Cooler cannot fit lower), **30 mm for all other modules**. Undersides are curved to the shell with a uniform 3 mm TPU saddle — no stilts or gaps > 5 mm. All external edges rounded (fillet ≥ 3 mm), no sharp points. |
| P3 | **Assist, never replace** | The helmet complements the white cane or guide dog. Docs and first-boot voice message say so. |
| P4 | **Silence must never mean "safe" when broken** | Every subsystem is watched. A failure produces a distinct FAULT pattern (§5.7, §6.2). |
| P5 | **Safety path independent of AI** | The LiDAR reflex path (§5.1) runs without the camera or neural networks. |
| P6 | **Offline first** | All hazard warnings are computed on the helmet. The phone/internet is only for location, SOS and optional services. |
| P7 | **Buildable worldwide** | Only globally available parts (AliExpress, DigiKey, Mouser, Pimoroni, local Raspberry Pi resellers). No soldering in the reference build (Dupont/JST connectors). Parts printable on a 220×220×250 mm FDM printer. |
| P8 | **Accessible by default** | Tactile buttons with distinct shapes, voice prompts in the user's language (ko, en first), screen-reader friendly phone app. |
| P9 | **Permissive licences** | Only Apache-2.0 / MIT / BSD models and libraries in the default build (no AGPL). |

---

## 2. Patent feature mapping

| Patent element (paragraph) | v1.0 implementation | Status |
|---|---|---|
| Case 110 — helmet | Certified helmet + printed clip-on modules | v1.0 |
| Camera 120 / image module 121 — hazard recognition, approaching objects [0033] | Camera Module 3 Wide + NanoDet-Plus detector + tracker + time-to-contact | v1.0 |
| Stairs / cliff on walking path [0033] | Down-looking LiDAR drop-off detector (§5.2) | v1.0 |
| Character recognition 122 — signs [0035–0036] | Button-triggered OCR (RapidOCR, optional package) | v1.0 (optional install) |
| Elevator buttons + hand guidance [0037] | OCR of button labels + hand tracking | Roadmap v1.2 |
| Face recognition 123 — acquaintance / person to avoid, with mask [0038–0040] | YuNet + SFace, local enrolment database, "friend" / "avoid" tags | v1.0 |
| Accessible facility recognition [0034] | Custom-trained detector (tactile paving, ramps, crossings) | Roadmap v1.3 (needs dataset) |
| Rain / fog removal [0033] | Lightweight dehaze pre-filter (CLAHE-based) | v1.0 basic, learned model roadmap |
| Four cameras or 360° camera [0032] | One front wide camera; rear camera expansion port | v1.0 front, rear roadmap |
| Vibration unit 130 — side-specific, intensity/pattern, count pulses [0041–0044] | 3 coin ERM motors (L / C / R), haptic language §6 | v1.0 |
| Speaker unit 140 — voice by signal type [0045–0049] | USB audio → open-ear / bone-conduction headset, priority speech queue | v1.0 |
| Position sensor 150, dangerous-area warning [0051] | Phone GPS via BLE; optional helmet GPS (UART) | v1.0 phone, helmet GPS optional |
| Navigation 160 [0054–0056] | Destination beacon + integration with existing accessible navigation apps | Roadmap v1.1 |
| Communication 170 + emergency report 112/119 [0057–0059] | BLE link to phone app; SOS by long-press or fall detection; app offers one-tap call/SMS with location | v1.0 (user confirms call — web platform limit) |
| Microphone 180, voice call [0060–0061] | Headset mic via phone Bluetooth audio | v1.0 via phone |
| Fan, removable rechargeable battery [0028–0029] | USB-C power bank in pocket/waist bag with breakaway cable; passive vents | v1.0 |
| Air-curtain module 111 [0062–0064] | Concept + experimental module docs only (power/noise) | Experimental |
| Flow-channel module 112 + nozzle 113 [0065–0068] | Printed TPU rain gutter segments + rear nozzle (passive, no power) | v1.0 optional print |

---

## 3. System architecture

```
                 ┌──────────────────────────── HELMET ────────────────────────────┐
                 │                                                                │
 Camera Module 3 ─┤► vision thread: capture → dehaze → detector → tracker → TTC ──┐│
 Wide (CSI)       │                          └► faces (on demand / low rate)      ││
                  │                          └► OCR (button-triggered)            ││
 TF-Luna FWD ─I2C─┤► reflex thread 50 Hz: head-height obstacle zones ────────────┤│
 TF-Luna DOWN ─I2C┤► reflex thread 50 Hz: drop-off / step detector ──────────────┤│
 MPU-6050 ────I2C─┤► imu thread 100 Hz: fall detection ──────────────────────────┤│
 3 buttons ──GPIO─┤► input thread: short / long / double press ──────────────────┤│
                  │                                                              ▼│
                  │                              EVENT BUS ──► hazard arbiter ─────┤
                  │                                               │                │
                  │           ┌───────────────────────────────────┼──────────┐     │
                  │           ▼                                   ▼          ▼     │
                  │   haptics (ULN2003 → 3 ERM)          audio (USB headset)  BLE link
                  │                                                              │ │
                  │  watchdog: heartbeats of every thread → FAULT events         │ │
                  └──────────────────────────────────────────────────────────────┼─┘
                                                                                 │ Nordic UART Service
                                                                   PHONE APP (PWA, Web Bluetooth)
                                                                   location · SOS · settings · log
```

Runtime: Raspberry Pi OS Bookworm 64-bit, Python ≥ 3.11, single process, one thread per
subsystem, thread-safe event bus. Runs as a systemd service with automatic restart.

---

## 4. Hardware reference design

### 4.1 Bill of materials (reference build)

| Ref | Part | Qty | Notes / global search keyword |
|---|---|---|---|
| H1 | Certified bicycle/multisport helmet with vents | 1 | EN 1078 / CPSC / KC mark. Size to user. Prefer rounded shell without visor. |
| U1 | Raspberry Pi 5, 4 GB (8 GB recommended) | 1 | Alternative: Raspberry Pi 4 4 GB (lower frame rate) |
| U2 | Raspberry Pi Active Cooler (official) | 1 | Required on Pi 5 |
| U3 | microSD 32 GB A2 (or NVMe via M.2 HAT) | 1 | |
| C1 | Raspberry Pi Camera Module 3 **Wide** (IMX708, 120°) | 1 | |
| C2 | Pi 5 camera cable 22-pin→15-pin, 300 mm | 1 | "Raspberry Pi 5 camera cable 300mm" |
| S1 | Benewake **TF-Luna** LiDAR (I2C mode) — forward | 1 | 0.2–8 m, 2° FOV |
| S2 | Benewake **TF-Luna** LiDAR (I2C mode) — down-looking | 1 | |
| S3 | MPU-6050 (GY-521) IMU | 1 | Fall detection |
| M1–M3 | Coin ERM vibration motor 10 × 2.7 mm, 3 V, with leads (type 1027) | 3 | Left / Center / Right |
| D1 | ULN2003 driver board (from 28BYJ-48 kit) | 1 | Drives the 3 motors |
| B1–B3 | 12 × 12 mm tactile button modules (3-pin) or bare 12 mm tactile switches + Dupont | 3 | Caps are printed with distinct shapes |
| L1 | 3 mm LED + 330 Ω (or LED module) | 1 | Status for sighted helpers |
| A1 | USB audio adapter with a real microphone input (not "line in") | 1 | Pi 5 has no 3.5 mm jack. Match the headset plug: a 4-pole (TRRS, CTIA) combo jack, or separate headphone + mic jacks plus a TRRS→2×TRS splitter |
| A2 | Open-ear / bone-conduction wired headset with mic | 1 | Must not block ambient sound |
| P1 | USB-C power bank, PD, ≥ 5 V 3 A output, 10 000–20 000 mAh | 1 | Carried in pocket / waist bag |
| P2 | USB-C cable 1.5 m + magnetic breakaway USB-C adapter rated 3 A | 1 | Breakaway prevents neck snagging |
| W4 | USB-A male → female extension cable, 10–15 cm | 1 | Pi 5 USB 2.0 port → audio adapter in the aux pod |
| W1 | Dupont jumper wires F-F 20 cm (40-pack), **6-pin** 1.25 mm leads for TF-Luna (pin 5 is needed for I2C mode) | 1 set | |
| W3 | Dupont 1-to-N female splitter cables (or 2×8 female header splitter) for shared SDA, SCL, 5 V, 3.3 V and GND lines | 1 set | 3 I2C devices and several 5 V loads share header pins. **Not** a Qwiic/STEMMA QT hub: those are 3.3 V-only with 1 mm JST-SH plugs, while TF-Luna needs 5 V |
| W2 | 20 mm hook-and-loop straps (200 mm), 3M Dual Lock / VHB pads | 1 set | |
| F1 | M2.5 × 6 screws + 5 mm standoffs (Pi), M2 × 5 screws (camera, TF-Luna) | 1 set | |
| G1 | Optional: u-blox NEO-M8N GPS (UART) | 0–1 | Phone-free location |
| R1 | Optional: TPU filament for rain gutter and haptic pads | — | |

Printed parts: PETG or ASA for rigid parts (PLA softens in summer sun / hot cars); TPU 95A for
haptic pads, saddles and rain gutter. Strap anchors are PETG.

### 4.2 Raspberry Pi 5 pin map (BCM numbering) — **authoritative**

| Function | BCM GPIO | Header pin | Direction | Notes |
|---|---|---|---|---|
| I2C1 SDA | GPIO2 | 3 | bus | TF-Luna FWD 0x10, TF-Luna DOWN 0x11, MPU-6050 0x68 |
| I2C1 SCL | GPIO3 | 5 | bus | 400 kHz (`dtparam=i2c_arm=on,i2c_arm_baudrate=400000`) |
| Haptic LEFT | GPIO17 | 11 | out | → ULN2003 IN1 → M1 |
| Haptic CENTER | GPIO27 | 13 | out | → ULN2003 IN2 → M2 |
| Haptic RIGHT | GPIO22 | 15 | out | → ULN2003 IN3 → M3 |
| Button B1 (circle) | GPIO5 | 29 | in, pull-up | active-low |
| Button B2 (triangle) | GPIO6 | 31 | in, pull-up | active-low |
| Button B3 (square) | GPIO26 | 37 | in, pull-up | active-low |
| Status LED | GPIO16 | 36 | out | via 330 Ω |
| GPS TX→Pi RX (optional) | GPIO15 | 10 | in | UART0, 9600 baud |
| GPS RX←Pi TX (optional) | GPIO14 | 8 | out | |
| 5 V | — | 2, 4 | power | ULN2003 +, TF-Luna ×2 (5 V). **Never power button modules from 5 V** (5 V on a GPIO damages the Pi) |
| 3.3 V | — | 1, 17 | power | MPU-6050, button modules (**3.3 V required**; modules must be active-low, otherwise set `buttons.active_high: true` — an unconfigured active-high module reads as permanently pressed) |
| GND | — | 6, 9, 14, 20, 25, 30, 34, 39 | | Common ground |

- **TF-Luna I2C mode:** connector pin 5 (configuration) tied to GND selects I2C. TF-Luna logic is
  3.3 V-compatible; power at 5 V. The down-looking unit's address is changed once from 0x10 to 0x11
  with `python -m owsh.tools.tfluna_addr --from 0x10 --to 0x11`.
- **ERM motors on ULN2003:** motor + to ULN2003 board "+" (5 V) and motor − to OUT1..OUT3.
  The ULN2003 Darlington drop (~1 V) gives ≈ 4 V; firmware caps PWM duty at 75 % (`haptics.max_duty`)
  so 3 V motors are not overdriven.
- **Camera:** CAM/DISP 0 connector on Pi 5.
- **Audio:** USB audio adapter in any USB 2.0 port (keep USB 3 ports free to reduce 2.4 GHz noise near BLE).
- **Power budget:** Pi 5 loaded ≈ 6.5 W, peripherals ≈ 1.5 W → ≈ 8 W. A 3 A supply limits USB
  peripherals to 600 mA which is sufficient. 10 000 mAh ≈ 3.5 h, 20 000 mAh ≈ 7 h (conservative).

### 4.3 Mechanical layout and mass budget

| Module | Location on helmet | Contents | Attachment | Mass budget |
|---|---|---|---|---|
| Front sensor pod | Front-top, centred, above forehead | C1 camera facing forward tilted 10° down, S1 LiDAR forward horizontal, S2 LiDAR tilted down 50° from horizontal | 2 × 20 mm straps (slot 21 × 3.2 mm) through front vents + Dual Lock on a 3 mm TPU saddle | ≤ 60 g (printed ≈ 40 g); curved bar 108 × 42 mm; height ≤ 35 mm |
| Main case | Top, behind the crown, long axis front-to-back | U1 + U2, S3 IMU, L1 LED window | 2 × 20 mm straps through vents + Dual Lock on a 3 mm TPU saddle | ≤ 150 g incl. Pi (printed ≈ 52 g); 99 × 63 mm; height ≤ 40 mm |
| Aux pod | Back of the head, below the main case | D1 ULN2003 driver, A1 USB audio adapter (via W4 extension) | Straps + Dual Lock on 3 mm TPU saddle | ≤ 70 g (printed ≈ 30 g); 99 × 38 mm; height ≤ 30 mm |
| Button module | Right side, above ear, lower rim | B1 front, B2 middle, B3 rear | Strap anchor + Dual Lock | ≤ 25 g; height ≈ 21 mm |
| Haptic pads ×3 | Inside, on comfort pads: left temple, forehead centre, right temple | M1, M2, M3 | Hook-and-loop to helmet comfort padding (do not glue to EPS) | ≤ 15 g total |
| Rain gutter (optional) | Along lower shell rim, sloping front → rear nozzle | TPU segments | Clips over rim + straps | ≤ 60 g |
| Cables | Along shell under straps | camera FPC in printed cover, Dupont bundles | Cable clips | ≤ 30 g |

Total added mass ≤ 380 g without the rain gutter (estimated ≈ 330 g; the optional gutter adds ≈ 95 g — lighter gutter is a roadmap item). Battery is not on the helmet. Keep the centre of mass near the helmet
centre: front pod and main case balance each other.

### 4.4 Key component dimensions (verify with calipers — all are OpenSCAD parameters)

| Component | Dimensions | Mounting |
|---|---|---|
| Raspberry Pi 5 | PCB 85 × 56 × 1.6 mm; height incl. Active Cooler ≈ 22 mm above PCB bottom | 4 × M2.5 holes, 3.5 mm from edges, pitch 58 × 49 mm |
| Camera Module 3 Wide | PCB 25 × 24 mm, depth ≈ 12.4 mm incl. lens | 4 × M2 holes, pitch 21 × 12.5 mm, top holes 2 mm below top edge; lens centre 9.5 mm below top edge |
| TF-Luna | 35 × 21.25 × 13.5 mm, 5 g | cradle + 2 × M2 holes (verify), clear aperture: never cover lens |
| MPU-6050 GY-521 | 21 × 16 × 3 mm | 2 × 3 mm holes |
| ULN2003 board | 35 × 32 × 15 mm | 4 × 3 mm holes (varies) — cradle design |
| USB audio adapter | ≈ 50 × 18 × 10 mm | cradle |
| Coin ERM 1027 | Ø 10 × 2.7 mm | pocket in TPU pad |
| Tactile switch 12 × 12 | 12 × 12 × 7.3 mm (plus cap stem) | pocket |
| Helmet shell (design envelope) | local radius 95–130 mm, vents ≥ 20 × 8 mm | TPU saddles conform to curvature |

---

## 5. Sensing and hazard logic

### 5.1 Reflex path — forward LiDAR (head-height obstacles)

Head-height obstacles (branches, truck mirrors, signs, open windows) are what a cane misses.
Loop 50 Hz, median of last 3 samples. Invalid reading (strength < 100 or distance = 0)
counts as "no return".

| Zone | Distance | Haptic (CENTER motor) | Voice |
|---|---|---|---|
| Z3 notice | 2.0 m ≥ d > 1.2 m | 2 Hz short pulses, 40 % | none |
| Z2 warning | 1.2 m ≥ d > 0.6 m | 5 Hz pulses, 70 % | "Obstacle ahead" once per 5 s |
| Z1 imminent | d ≤ 0.6 m | continuous 100 % | "Stop" (preempts) |

Hysteresis 0.1 m between zones. Zone thresholds are config values.
Near-range dropout: the TF-Luna returns nothing below 0.2 m. If the reading was in Z1 and becomes
no-return, Z1 is **held for 0.5 s** instead of going silent.

### 5.2 Reflex path — down-looking LiDAR (drop-off and steps)

Tilt θ = 50° below horizontal (config `dropoff.tilt_deg`). While walking on level ground the
expected distance d₀ is learned as a rolling median over 3 s of samples whose variance is low
(auto-calibration, clamped to 1.2–3.5 m). **Safety rule:** d₀ is never automatically increased while
longer distances are measured (standing still at a platform edge must not teach the track bed as ground);
a shorter stable ground distance is re-learned after 10 s (e.g. sitting down, slope).

- **DROP (stairs down, curb, platform edge):** d > d₀ × 1.30 **or** no-return, sustained ≥ 120 ms
  → P1 IMMINENT, all motors double long pulse, voice "Step down ahead" / "Drop ahead".
- **STEP UP / low obstacle:** d < d₀ × 0.70 sustained ≥ 120 ms → P2 WARNING, center motor
  3 short pulses, voice "Step up ahead".
- Cooldown 3 s per type. No-return on very dark / wet surfaces is reported as DROP because a missed
  drop is worse than a false alarm; users can lower sensitivity (`dropoff.no_return_is_drop: false`).

### 5.3 Vision path

- Capture 1280 × 720 → resize for detector. Target ≥ 8 FPS on Pi 5.
- Pre-filter: optional CLAHE on luminance for fog/rain/low light (`vision.dehaze: auto|on|off`).
- Detector: **NanoDet-Plus-m 416** (OpenCV Zoo `object_detection_nanodet_2022nov.onnx`,
  Apache-2.0) via `cv2.dnn`. Any compatible ONNX can be configured.
- Classes of interest (COCO): person, bicycle, car, motorcycle, bus, truck, dog, horse,
  bench, fire hydrant, stop sign, parking meter, traffic light, chair, potted plant, suitcase.
  "Movers" = person, bicycle, car, motorcycle, bus, truck, dog, horse.
- Tracker: IoU-greedy tracker, track kept 0.7 s without detections.
- Direction: horizontal angle from bbox centre using camera HFOV (Camera Module 3 Wide: 102°).
  LEFT < −15° ≤ CENTER ≤ +15° < RIGHT.
- Time-to-contact: TTC = Δt / (s − 1), s = bbox-height ratio over ≥ 0.4 s window (smoothed).
- Alerts:
  - **APPROACH P1:** mover with TTC < 1.5 s and bbox height > 20 % of frame.
  - **APPROACH P2:** mover with TTC < 3.0 s (vehicles: < 4.0 s) and bbox height > 10 % of frame.
  - The condition must hold on **2 consecutive processed frames** (suppresses bounding-box jitter).
- Per-track cooldown 5 s for the same level; escalation to a higher level bypasses cooldown.
- Detector input colour order is configurable (`color_order: rgb|bgr`, default rgb as in the OpenCV Zoo demo).
- **Describe scene (button):** up to 5 objects sorted by closeness (bbox height), grouped by
  class and direction: "2 people ahead, bicycle on the right".

### 5.4 Faces

- YuNet 2023mar detector + SFace 2021dec recogniser (OpenCV Zoo, MIT / Apache-2.0).
- Runs at ≤ 2 Hz on the most recent frame when persons are detected.
- Enrolment DB: `data/faces/<name>/{*.jpg}` + `data/faces/index.json` with `tag: friend|avoid`.
  Enrol with `python -m owsh.tools.enroll_face --name "Mina" --tag friend --camera 0` (or images).
- Match: cosine similarity ≥ 0.363 (SFace recommended threshold). Mask handling: accept
  partial faces if YuNet confidence ≥ 0.6; lower similarity threshold is configurable.
- friend → P3 INFO "Mina is ahead on the left", 2 short pulses on that side, cooldown 60 s per person.
- avoid → P2 WARNING with voice, cooldown 60 s.
- Privacy: embeddings and photos never leave the helmet; not sent over BLE except the name.

### 5.5 OCR (button-triggered)

- Backend `rapidocr_onnxruntime` (Apache-2.0) when installed, languages from config; otherwise
  voice "Text reading is not installed".
- Reads the centre 70 % crop of a fresh frame, orders lines top→bottom, speaks up to 200 characters.
  Long-press B1 repeats the last spoken message.
- Signs containing danger keywords (config list per language, e.g. "위험", "공사", "DANGER",
  "CAUTION", "WET FLOOR") are prefixed with "Warning sign:".

### 5.6 Fall detection (IMU)

- Free-fall |a| < 0.35 g for ≥ 80 ms followed by impact |a| > 2.5 g within 1 s, then
  low motion (|a| within 1 ± 0.15 g) for 2 s → FALL → SOS countdown (§7.3).

### 5.7 Watchdog

Each thread publishes a heartbeat. Timeouts: camera frames 2 s, LiDAR 0.5 s, IMU 1 s, audio
backend init failure immediate.

**Camera blocked / blind camera:** frames still arrive but the lens is covered (mud, rain film,
sticker, cap) or it is pitch dark. If mean luminance < 12 (0–255) **and** luminance std-dev < 6
for ≥ 3 s, **or** ≥ 97 % of pixels are darker than 12 for ≥ 3 s (privacy-shutter frames with a small
icon), raise FAULT `camera_blocked` (voice: "Camera is covered or too dark"). Also raise it
when the Laplacian variance (sharpness) stays < 5 for ≥ 5 s (smeared lens). The LiDAR reflex
path keeps working and the voice says so ("Distance sensors still active").

**Power and temperature (Pi):** poll the firmware `get_throttled` flags every 5 s. Under-voltage
(bit 0) continuously for ≥ 10 s → P2 "Power is low. Charge the battery soon." (at most once per
5 min). CPU ≥ 80 °C → P2 "Helmet is overheating." (at most once per 5 min, re-armed below 75 °C). Failure → FAULT event (component id). FAULT repeats every 10 s (P0) while active **for safety-relevant components** (camera, LiDARs,
haptics, IMU). Non-safety components (faces, OCR, BLE, config) are announced once at P2. Recovery → voice "<component> recovered".

---

## 6. Haptic language (motors L = left temple, C = forehead, R = right temple)

### 6.1 Priorities

| Level | Name | Examples | Preempts |
|---|---|---|---|
| P0 | CRITICAL | SOS countdown, system FAULT | everything |
| P1 | IMMINENT | Z1 obstacle, DROP, APPROACH P1 | P2–P4 |
| P2 | WARNING | Z2 obstacle, STEP UP, APPROACH P2, avoid-person | P3–P4 |
| P3 | INFO | Z3 notice, friend face, OCR result, scene description | P4 |
| P4 | STATUS | ready, button tick, mute toggled | — |

The haptic mixer renders every active pattern per motor and takes the **maximum** intensity per
motor at each 10 ms tick (continuous reflex patterns and one-shot patterns coexist). Audio uses
strict preemption (§7.1).

### 6.2 Pattern table (authoritative)

| Pattern id | Motors | Timing | Meaning |
|---|---|---|---|
| `tick` | C | 40 ms @ 60 % | Button acknowledged / "I'm alive" |
| `zone3` | C | repeat: 60 ms on / 440 ms off @ 40 % | Obstacle 1.2–2.0 m |
| `zone2` | C | repeat: 80 ms on / 120 ms off @ 70 % | Obstacle 0.6–1.2 m |
| `zone1` | C | continuous @ 100 % | Obstacle ≤ 0.6 m |
| `drop` | L+C+R | 2 × (400 ms on / 150 ms off) @ 100 % | Drop-off / stairs down |
| `step_up` | C | 3 × (100 ms on / 100 ms off) @ 80 % | Step up / low obstacle |
| `approach_left` / `approach_right` / `approach_center` | L / R / C | 3 × (150 ms on / 80 ms off) @ 100 % (P1) or 70 % (P2) | Moving object approaching from that side |
| `person_friend_<side>` | side | 2 × (80 ms on / 120 ms off) @ 60 % | Enrolled friend |
| `person_avoid_<side>` | side | 4 × (60 ms on / 60 ms off) @ 90 % | Enrolled person to avoid |
| `turn_left` / `turn_right` | L / R | 250 ms on / 750 ms off, repeat while active @ 70 % | Steering cue (navigation, roadmap) |
| `count_n` | C | n × (120 ms on / 280 ms off) @ 70 %, n ≤ 10 | Number (e.g. floor) [0044] |
| `sos_countdown` | L+C+R | 1 Hz 200 ms @ 100 % for 10 s | SOS will be sent |
| `fault` | C | 3 × (50 ms on / 50 ms off) @ 100 %, every 10 s | A subsystem failed — do not trust silence |
| `ready` | L → C → R | 100 ms each, sequential @ 60 % | Boot complete |

---

## 7. Audio, buttons, SOS

### 7.1 Speech

- Backends in order: `piper` CLI (if configured, natural voices), `espeak-ng` (Pi default, supports ko/en),
  `pyttsx3` (desktop development). Pre-rendered clips cached as WAV under `data/cache/tts/` for fixed phrases.
- Queue: a higher-priority message interrupts the current one; same or lower priority waits;
  queued P1/P2 messages older than 2 s are dropped; at most 3 queued items.
- Mute (B3 double press) silences P3–P4 speech only. P0–P2 are always spoken. **Answers to a button
  request (read text, describe, status, where am I, who is here) are spoken even when muted.**
- All phrases live in `owsh/i18n/<lang>.json` keyed by message id; `{placeholders}` allowed.

### 7.2 Buttons (B1 front ○ circle, B2 middle △ triangle, B3 rear □ square)

| Button | Short press (< 0.8 s) | Long press (≥ 1.5 s) | Double press (< 0.4 s gap) |
|---|---|---|---|
| B1 ○ | Read text (OCR) | Repeat last message | — |
| B2 △ | Describe scene | Where am I (location from phone) | Who is here (faces) |
| B3 □ | Status report | Hold 3 s: SOS countdown | Toggle voice mute (P3–P4) |

Timing: presses between 0.8 s and the long threshold are ignored. B3's long press is 3 s and fires
while still held. Every accepted press gives `tick` immediately. During SOS countdown any button cancels.

**Safe shutdown:** hold **B1 ○ + B3 □ together for 5 s** (press both within about 1 s) → voice
"Shutting down" + `ready` pattern reversed (R→C→L) → power off after 3 s. While both are held, the
B3 SOS long press and B1 long press are suppressed; releasing either early aborts.

### 7.3 SOS

1. Trigger: B3 hold 3 s, or FALL.
2. Countdown 10 s: `sos_countdown` + voice "Emergency alert in 10 seconds. Press any button to cancel."
3. If not cancelled: send `sos` over BLE (repeat every 5 s until phone acks), voice "Sending emergency alert";
   "Emergency alert sent" is spoken only after the phone's `ack`.
4. Phone app: loud alarm + vibration, shows location, big buttons "Call emergency number"
   (per-country setting: 112 / 119 / 911 …) and "Send SMS to guardians" (prefilled with map link).
   The web platform requires the user (or a bystander) to confirm the call/SMS; a native app can automate it (roadmap).
5. If no phone is connected: voice "Phone not connected" every 10 s and `sos_countdown` pattern continues
   for 60 s so bystanders notice (LED blinks fast). Any button press cancels.

---

## 8. Helmet ↔ phone protocol (BLE, Nordic UART Service)

- Service `6E400001-B5A3-F393-E0A9-E50E24DCCA9E`
- RX (phone → helmet, write / write-without-response) `6E400002-B5A3-F393-E0A9-E50E24DCCA9E`
- TX (helmet → phone, notify) `6E400003-B5A3-F393-E0A9-E50E24DCCA9E`
- Device name: `OWSH-XXXX` (last 4 hex of the Bluetooth MAC).
- Framing: UTF-8 JSON objects terminated by `\n`. Messages longer than the negotiated MTU − 3
  are split into chunks; the receiver buffers until `\n`. Max message 1024 bytes.
- Every message has `"t"` (type) and `"v": 1` (protocol version). Helmet messages carry `"ts"` (unix ms).

### 8.1 Helmet → phone

| t | Fields | When |
|---|---|---|
| `hello` | `fw`, `lang`, `features` [list] | on connect |
| `status` | `uptime_s`, `cpu_temp_c`, `fps`, `faults` [list], `muted` | every 10 s and on change |
| `alert` | `id`, `level` 0–4, `kind` (`obstacle`,`drop`,`step_up`,`approach`,`face`,`sign`,`fault`), `dir` (`left`,`center`,`right`,`all`), `dist_m`?, `label`?, `text` | each spoken/haptic alert ≥ P3 |
| `speech` | `text`, `level` | everything spoken (for the app's accessible log) |
| `sos` | `id`, `reason` (`button`,`fall`), `state` (`countdown`,`sent`,`cancelled`) | SOS flow |
| `need_location` | — | B2 long press |
| `pong` | `id` | reply to ping |

### 8.2 Phone → helmet

| t | Fields | Effect |
|---|---|---|
| `loc` | `lat`, `lon`, `acc_m`, `addr`? | Latest location; `addr` spoken for "Where am I" if present |
| `ack` | `id` | Acknowledges `sos` |
| `say` | `text`, `level` (default 3) | Speak text through the helmet |
| `cfg` | `lang`?, `muted`?, `volume`? (0–100), `dropoff_sensitivity`? (`low`,`normal`,`high`) | Update settings at runtime |
| `ping` | `id` | Liveness |

Unknown types are ignored (forward compatibility).

`status` also carries `undervoltage` and `throttled` (booleans, omitted when unknown).

### 8.3 Security
- The helmet requires an **encrypted, bonded** BLE link: RX has `encrypt-write`, TX has
  `encrypt-read` + `encrypt-notify` (Just Works pairing — the helmet has no display). The phone OS shows
  a standard pairing dialog on first connection.
- `ble.bonded_only: true` (default): messages from non-bonded devices are dropped. Pairing is open while
  no phone is bonded, and afterwards only for 120 s after each boot. A new pairing is announced by voice.
- Safety-reducing `cfg` changes are always confirmed aloud at P2 (heard even when muted): mute on,
  drop-off sensitivity low, volume set below 30 %.
- `say` from the phone is capped at P2 (can never interrupt P0/P1 speech) and rate-limited to 1 per 3 s.

---

## 9. Software layout and interfaces

```
firmware/
  pyproject.toml            # package "owsh"; extras: pi, ocr, ble, dev
  config/default.yaml       # all thresholds from this spec
  owsh/__main__.py          # python -m owsh [--config path] [--sim] [--video file] [--no-window]
  owsh/app.py               # wires threads, bus, arbiter, watchdog
  owsh/config.py            # dataclass config + YAML loader + validation
  owsh/events.py            # Event types, Level enum (P0..P4)
  owsh/bus.py               # thread-safe publish/subscribe
  owsh/arbiter.py           # hazard → haptic pattern + speech decisions, cooldowns
  owsh/i18n/__init__.py, ko.json, en.json
  owsh/vision/camera.py     # Picamera2 | OpenCV index | video file
  owsh/vision/preprocess.py # dehaze/CLAHE
  owsh/vision/detector.py   # NanoDet-Plus ONNX (cv2.dnn), class filter
  owsh/vision/tracker.py    # IoU tracker + TTC
  owsh/vision/describe.py   # scene description text
  owsh/vision/faces.py      # YuNet + SFace + DB
  owsh/vision/ocr.py        # RapidOCR optional
  owsh/sensors/tfluna.py    # I2C driver (smbus2) + simulated
  owsh/sensors/reflex.py    # zone logic (5.1) + drop-off logic (5.2)
  owsh/sensors/imu.py       # MPU-6050 driver + fall detector (5.6)
  owsh/output/haptics.py    # pattern engine + mixer; backends: gpiozero PWM | sim
  owsh/output/audio.py      # speech queue; piper | espeak-ng | pyttsx3 | print
  owsh/input/buttons.py     # gpiozero | keyboard (sim)
  owsh/link/ble.py          # NUS GATT server via "bless"; no-op when unavailable
  owsh/link/protocol.py     # message encode/decode/chunking (pure, tested)
  owsh/watchdog.py
  owsh/sim/dashboard.py     # desktop debug window: video, boxes, motor bars, sim LiDAR sliders
  owsh/tools/download_models.py, enroll_face.py, tfluna_addr.py, bench.py
  tests/                    # pytest: arbiter, reflex, dropoff, tracker/TTC, haptic mixer, protocol, buttons, fall
  scripts/setup_pi.sh       # apt + venv + config.txt I2C + systemd
  systemd/owsh.service
hardware/
  openscad/lib/*.scad       # common: rounded boxes, saddle, strap slots, parameters
  openscad/*.scad           # one file per printable part
  stl/                      # rendered outputs (committed for non-CAD users)
  renders/                  # PNG previews
  wiring/                   # wiring diagram (SVG) + pin table
app/                        # PWA: index.html, app.js, protocol.js, i18n/, sw.js, manifest
docs/en, docs/ko            # guides
```

**Simulation mode (`--sim`)** runs on any PC with a webcam or a video file: LiDARs and IMU are
simulated from dashboard sliders/keys, haptics are drawn as bars and printed, buttons are keys
(`1`/`2`/`3` short, `Shift+1..3` or `q`/`w`/`e` long, `a`/`s`/`d` double), speech uses pyttsx3.

---

## 10. Printable parts list (OpenSCAD, parametric)

| File | Part | Material | Qty | Notes |
|---|---|---|---|---|
| `front_pod_base.scad` | Front pod body with camera bay (10° down), forward LiDAR bay, down LiDAR bay (50°) | PETG/ASA | 1 | Rain lip above lenses, strap slots 21 × 3 mm |
| `front_pod_cover.scad` | Rear cover with FPC and cable exit | PETG/ASA | 1 | |
| `main_case_base.scad` | Pi 5 case base with standoffs, IMU, ULN2003 and audio adapter bays, vents | PETG/ASA | 1 | Opening for USB-C power and cooler exhaust facing down/back |
| `main_case_lid.scad` | Lid with LED light pipe hole and drip edge | PETG/ASA | 1 | |
| `aux_pod_base.scad` | Aux pod base: ULN2003 and USB audio adapter cradles | PETG/ASA | 1 | Curved underside |
| `aux_pod_lid.scad` | Aux pod lid | PETG/ASA | 1 | |
| `saddle_pad.scad` | Conformal TPU saddle (param. curvature) under pod/case | TPU | 2 | |
| `button_module.scad` | Button housing for 3 × 12 mm switches | PETG | 1 | |
| `button_caps.scad` | Caps ○ △ □ with raised tactile edges | PETG | 1 set | |
| `haptic_pad.scad` | Coin-motor pad with Velcro recess | TPU | 3 | |
| `strap_anchor.scad` | 20 mm strap anchor / buckle | PETG | 4 | |
| `cable_clip.scad` | Cable clip for FPC cover and Dupont bundles | PETG | 6 | |
| `fpc_cover.scad` | Camera cable cover channel | PETG | 1 | |
| `rain_gutter_segment.scad` | Flow-channel segment (front high → rear low), clip-over-rim | TPU | 4 | Patent 112 |
| `rain_nozzle_rear.scad` | Rear nozzle collecting both sides | TPU | 1 | Patent 113 |
| `assembly_preview.scad` | Whole assembly on a helmet envelope (not printed) | — | — | For renders |

Curved-underside parts (front pod, main case, aux pod) need slicer supports from the build plate under the curved face. The saddle/pod curvature is set at print time by `helmet_radius` / `helmet_radius_long` — measure the helmet first.

Print settings (reference): 0.2 mm layers, 4 walls, 25 % gyroid infill (rigid), TPU 100 % walls
(3) 15 % infill, supports only under curved undersides (other overhangs ≤ 45°), PETG 240 °C / 80 °C.

---

## 11. Verification plan (summary)

| ID | Test | Pass criterion |
|---|---|---|
| T1 | Unit tests `pytest` | all pass |
| T2 | Reflex latency LiDAR → motor | ≤ 60 ms (log timestamp) |
| T3 | Vision FPS on Pi 5 | ≥ 8 FPS NanoDet 416 |
| T4 | Head-height obstacle (branch mock at 1.8 m) | Z2 before 1.2 m, Z1 before 0.6 m, 20/20 trials |
| T5 | Stairs down (5 staircases, day/night) | DROP before first step edge 19/20 |
| T6 | Approaching bicycle / person | APPROACH alert with TTC ≥ 1.5 s, 18/20 |
| T7 | False alarm rate, 30 min city walk | ≤ 2 P1 false alarms / 10 min |
| T8 | Fault injection: unplug camera / LiDAR; cover the lens | FAULT within 3 s for unplug (2 s frame timeout), within 4 s for covered lens, within 1 s for LiDAR |
| T9 | SOS: hold B3, fall on mattress | countdown, phone receives `sos` |
| T10 | Battery 20 000 mAh continuous | ≥ 6 h |
| T11 | Impact: added modules detach / do not penetrate | visual check after 1 m drop of helmet on headform; never certification-test a modified helmet for sale without an accredited lab |
| T12 | User trials with blind walkers + O&M instructor | qualitative report, safety incidents = 0 |

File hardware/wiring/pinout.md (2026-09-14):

<!-- SPDX-License-Identifier: CERN-OHL-P-2.0 -->
<!-- Copyright 2026 CLSOFTLAB (씨엘소프트랩), Dr. Lee Il-guk (이일국) -->

# OWSH v1.0 — Raspberry Pi 5 pin map (BCM numbering)

This table is copied from the authoritative spec, `docs/en/00-system-design-spec.md` §4.2.
If the two ever differ, **the spec wins**: change the spec first, then this file, the SVG and the firmware.
Diagram: [`wiring_diagram.svg`](wiring_diagram.svg).

| Function | BCM GPIO | Header pin | Direction | Notes |
|---|---|---|---|---|
| I2C1 SDA | GPIO2 | 3 | bus | TF-Luna FWD 0x10, TF-Luna DOWN 0x11, MPU-6050 0x68 |
| I2C1 SCL | GPIO3 | 5 | bus | 400 kHz (`dtparam=i2c_arm=on,i2c_arm_baudrate=400000`) |
| Haptic LEFT | GPIO17 | 11 | out | → ULN2003 IN1 → M1 |
| Haptic CENTER | GPIO27 | 13 | out | → ULN2003 IN2 → M2 |
| Haptic RIGHT | GPIO22 | 15 | out | → ULN2003 IN3 → M3 |
| Button B1 (circle) | GPIO5 | 29 | in, pull-up | active-low |
| Button B2 (triangle) | GPIO6 | 31 | in, pull-up | active-low |
| Button B3 (square) | GPIO26 | 37 | in, pull-up | active-low |
| Status LED | GPIO16 | 36 | out | via 330 Ω |
| GPS TX→Pi RX (optional) | GPIO15 | 10 | in | UART0, 9600 baud |
| GPS RX←Pi TX (optional) | GPIO14 | 8 | out | |
| 5 V | — | 2, 4 | power | ULN2003 +, TF-Luna ×2 (5 V). **Never power button modules from 5 V** (5 V on a GPIO damages the Pi) |
| 3.3 V | — | 1, 17 | power | MPU-6050, button modules (**3.3 V required**; modules must be active-low, otherwise set `buttons.active_high: true` — an unconfigured active-high module reads as permanently pressed) |
| GND | — | 6, 9, 14, 20, 25, 30, 34, 39 | | Common ground |

- **TF-Luna I2C mode:** connector pin 5 (configuration) tied to GND selects I2C. TF-Luna logic is
  3.3 V-compatible; power at 5 V. The down-looking unit's address is changed once from 0x10 to 0x11
  with `python -m owsh.tools.tfluna_addr --from 0x10 --to 0x11`.
- **ERM motors on ULN2003:** motor + to ULN2003 board "+" (5 V) and motor − to OUT1..OUT3.
  The ULN2003 Darlington drop (~1 V) gives ≈ 4 V; firmware caps PWM duty at 75 % (`haptics.max_duty`)
  so 3 V motors are not overdriven.
- **Camera:** CAM/DISP 0 connector on Pi 5.
- **Audio:** USB audio adapter in any USB 2.0 port (keep USB 3 ports free to reduce 2.4 GHz noise near BLE).
- **Power budget:** Pi 5 loaded ≈ 6.5 W, peripherals ≈ 1.5 W → ≈ 8 W. A 3 A supply limits USB
  peripherals to 600 mA which is sufficient. 10 000 mAh ≈ 3.5 h, 20 000 mAh ≈ 7 h (conservative).

## Device-side connections (how the diagram wires each part)

The header pins below are the ones drawn in `wiring_diagram.svg`. Any pin of the same power/GND
group from the table above may be used instead. Shared SDA, SCL, 5 V, 3.3 V and GND lines are split with
the W3 Dupont splitter / small I2C hub (spec §4.1); TF-Luna needs the **6-pin** 1.25 mm lead (W1) because pin 5 is used.

| Device | Device pin | → Pi header pin | Wire colour |
|---|---|---|---|
| S1 TF-Luna FORWARD (0x10) | 1 +5V | 5 V rail (pin 2 / 4) | red |
| | 2 RXD/SDA | pin 3 (GPIO2 SDA) | blue |
| | 3 TXD/SCL | pin 5 (GPIO3 SCL) | yellow |
| | 4 GND | GND rail | black |
| | 5 configuration | GND rail (= I2C mode) | black |
| | 6 multiplexing output | not connected | — |
| S2 TF-Luna DOWN (0x11) | same as S1 | same as S1 | same |
| S3 MPU-6050 / GY-521 (0x68) | VCC | 3.3 V rail (pin 1 / 17) | orange |
| | GND | GND rail | black |
| | SCL / SDA | pin 5 / pin 3 | yellow / blue |
| | AD0 | open or GND (address 0x68) | — |
| D1 ULN2003 board | IN1 / IN2 / IN3 | pin 11 (GPIO17) / 13 (GPIO27) / 15 (GPIO22) | green |
| | + / − | 5 V rail / GND rail | red / black |
| M1 / M2 / M3 ERM 1027 | motor − | OUT1 / OUT2 / OUT3 | green |
| | motor + | ULN2003 board "+" (5 V) | red |
| B1 ○ / B2 △ / B3 □ | switch side A | pin 29 (GPIO5) / 31 (GPIO6) / 37 (GPIO26) | green |
| | switch side B | GND rail | black |
| 3-pin button module (alternative) | VCC / OUT / GND | **3.3 V only** (pin 1/17, never 5 V) / GPIO as above / GND; module must be active-low (else set `buttons.active_high: true`) | orange / green / black |
| L1 LED | anode via 330 Ω | pin 36 (GPIO16) | green |
| | cathode | GND rail | black |
| C1 Camera Module 3 Wide | 15-pin FPC | CAM/DISP 0 via C2 (22→15-pin, 300 mm) | FPC |
| A1 USB audio adapter | USB-A | a USB 2.0 port | — |
| P1 power bank | USB-C PD 5 V 3 A | Pi 5 USB-C via P2 magnetic breakaway | — |
| G1 GPS (optional) | TX / RX | pin 10 (GPIO15 RX) / pin 8 (GPIO14 TX) | purple |

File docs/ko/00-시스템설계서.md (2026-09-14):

# 오픈 보행 안전 헬멧 — 시스템 설계서 (v1.0)

> 오픈 보행 안전 헬멧 프로젝트 문서 · CC BY 4.0 라이선스 · © 2026 씨엘소프트랩(CLSOFTLAB), 이일국 박사

> **상태:** 참조 설계 v1.0 · **이 문서가 유일한 기준 문서(single source of truth)입니다.**
> 펌웨어, 3D 모델, 휴대폰 앱과 모든 가이드는 여기서 정한 핀 배치, 치수, 진동 언어, 통신 규약을
> 반드시 따라야 합니다. 바꿀 때는 이 문서를 먼저 고치고, 그다음 구현을 고칩니다.
>
> 이 문서는 영문 원문 [`../en/00-system-design-spec.md`](../en/00-system-design-spec.md)의 한국어판입니다.
> 두 문서가 다를 경우 영문 원문을 기준으로 하며, 차이를 발견하면 이슈로 알려 주십시오.

- 특허: 대한민국 등록특허 제10-2560496호 "주변 인식이 가능한 보행 안전 헬멧"
  (출원 제10-2021-0101227호, 2021-08-02 출원, 2023-07-24 등록)
- 특허권자 / 발명자 / 프로젝트 책임자: **씨엘소프트랩(CLSOFTLAB), 이일국 박사**
- 특허권자는 이 설계를 모든 사람에게 무상으로 공개합니다. [`PATENT_PLEDGE.md`](../../PATENT_PLEDGE.md)를 참고하십시오.
- 표어: *전 세계 시각장애인이 일반인처럼 다닐 수 있는 그날까지.*
  (Until the day blind people everywhere can walk like anyone else.)

### 프로젝트 공통 규칙
- 코드, 설계서, 이슈의 기본 언어는 **영어**입니다. 사용자용 가이드는 모두 **한국어**로도 제공합니다.
- 음성/화면 문구: `en`과 `ko`는 핵심 팀이 관리합니다. 다른 언어
  (`es`, `fr`, `pt`, `ar`, `hi`, `zh-CN`, `ja`, `sw`, …)도 환영하지만, 해당 언어가 모국어인 시각장애인이나
  보행지도사(O&M 전문가)의 검토를 거쳐야 **"검증됨(verified)"**으로 표시합니다. 안전 문구는 오해의 여지가
  없어야 하기 때문입니다. 검증되지 않은 언어는 첫 부팅 때 안내 문구와 함께 제공됩니다.
- 긴급 전화번호는 국가별 설정값이며, 특정 국가 번호로 코드에 고정하지 않습니다.
- 단위: 기본은 미터법이며, 음성 안내는 야드파운드법도 선택할 수 있습니다.

---

## 1. 목표와 설계 원칙

**목표:** 누구나 살 수 있고 출력할 수 있는 부품으로, 세계 어디서든 시각장애인과 저시력인이
비장애인처럼 자유롭고 안전하게 걸을 수 있게 합니다.

**안경이 아니라 헬멧인 이유:** 충돌이나 넘어짐이 결국 일어나더라도 헬멧은 머리를 보호합니다.
따라서 헬멧의 보호 기능은 **절대 양보할 수 없습니다**:

| # | 원칙 | 결과 |
|---|---|---|
| P1 | **충격 보호 성능을 절대 떨어뜨리지 않는다** | 인증받은 자전거/멀티스포츠 헬멧(EN 1078, CPSC 1203, AS/NZS 2063, KC 또는 동등 인증)을 사용합니다. 헬멧 외피(셸)를 3D 프린팅하지 않습니다. EPS 라이너나 외피에 구멍을 뚫거나, 자르거나, 접착하거나, 녹이지 않습니다. |
| P2 | **충격 시 떨어져 나가는 낮은 부착물** | 외부 모듈은 통풍구로 통과시킨 벨크로 스트랩 그리고/또는 떼어낼 수 있는 접착 패드로 붙여, 충격을 받으면 떨어져 나가게 합니다. 외피 위 최대 높이: **전방 포드 35 mm, 메인 케이스 40 mm**(Active Cooler를 단 Pi 5는 더 낮게 들어가지 않음), **그 밖의 모든 모듈 30 mm**. 바닥면은 외피 곡면에 맞춘 곡면이며 두께가 고른 3 mm TPU 새들 위에 놓습니다 — 받침 기둥이나 5 mm를 넘는 틈은 없어야 합니다. 바깥 모서리는 모두 둥글게(필렛 ≥ 3 mm), 날카로운 끝이 없어야 합니다. |
| P3 | **보조할 뿐, 대체하지 않는다** | 헬멧은 흰지팡이나 안내견을 보완합니다. 문서와 첫 부팅 음성 안내에서 이를 분명히 알립니다. |
| P4 | **고장 났을 때 침묵이 "안전"을 뜻해서는 안 된다** | 모든 하위 시스템을 감시합니다. 고장이 나면 구별되는 FAULT 패턴(§5.7, §6.2)을 냅니다. |
| P5 | **AI와 독립적인 안전 경로** | 라이다 즉시 경고 경로(reflex path, §5.1)는 카메라나 신경망 없이도 동작합니다. |
| P6 | **오프라인 우선** | 모든 위험 경고는 헬멧에서 계산합니다. 휴대폰/인터넷은 위치, 긴급 신고(SOS), 선택 기능에만 씁니다. |
| P7 | **전 세계 어디서나 제작 가능** | 전 세계에서 구할 수 있는 부품만 사용합니다(AliExpress, DigiKey, Mouser, Pimoroni, 각국 Raspberry Pi 리셀러). 참조 빌드는 납땜이 없습니다(듀폰/JST 커넥터). 부품은 220×220×250 mm FDM 프린터로 출력할 수 있습니다. |
| P8 | **기본부터 접근성** | 모양이 서로 다른 촉각 버튼, 사용자 언어의 음성 안내(ko, en 우선), 스크린 리더 친화적인 휴대폰 앱. |
| P9 | **허용적 라이선스** | 기본 빌드에는 Apache-2.0 / MIT / BSD 모델과 라이브러리만 사용합니다(AGPL 제외). |

---

## 2. 특허 구성요소 대응표

| 특허 구성요소 (문단) | v1.0 구현 | 상태 |
|---|---|---|
| 케이스부 110 — 헬멧 | 인증 헬멧 + 출력한 클립형 모듈 | v1.0 |
| 카메라부 120 / 영상모듈 121 — 위험 인식, 접근하는 물체 [0033] | Camera Module 3 Wide + NanoDet-Plus 검출기 + 추적기 + 충돌 예상 시간(TTC) | v1.0 |
| 보행 경로상의 계단 / 낭떠러지 [0033] | 아래를 보는 라이다 단차 검출기(§5.2) | v1.0 |
| 문자인식모듈 122 — 표지판 [0035–0036] | 버튼으로 실행하는 OCR(RapidOCR, 선택 설치 패키지) | v1.0 (선택 설치) |
| 엘리베이터 버튼 + 손 안내 [0037] | 버튼 표시 OCR + 손 추적 | 로드맵 v1.2 |
| 얼굴인식모듈 123 — 지인 / 기피 대상, 마스크 착용 시 포함 [0038–0040] | YuNet + SFace, 헬멧 내부 등록 데이터베이스, "friend"(지인) / "avoid"(기피) 태그 | v1.0 |
| 장애인용 시설 인식 [0034] | 직접 학습한 검출기(점자블록, 경사로, 횡단보도) | 로드맵 v1.3 (데이터셋 필요) |
| 우천 / 안개 제거 [0033] | 가벼운 안개 제거 전처리 필터(CLAHE 기반) | v1.0 기본, 학습 모델은 로드맵 |
| 카메라 4대 또는 360° 카메라 [0032] | 전방 광각 카메라 1대; 후방 카메라 확장 포트 | v1.0 전방, 후방은 로드맵 |
| 진동부 130 — 좌우 구분, 세기/패턴, 횟수 진동 [0041–0044] | 코인형 ERM 모터 3개(L / C / R), 진동 언어 §6 | v1.0 |
| 스피커부 140 — 신호 종류별 음성 [0045–0049] | USB 오디오 → 오픈형 / 골전도 헤드셋, 우선순위 음성 대기열 | v1.0 |
| 위치센서부 150, 위험 지역 경고 [0051] | BLE로 받은 휴대폰 GPS; 헬멧 GPS(UART)는 선택 | v1.0 휴대폰, 헬멧 GPS 선택 |
| 네비게이션부 160 [0054–0056] | 목적지 방향 안내 + 기존 접근성 내비게이션 앱과 연동 | 로드맵 v1.1 |
| 통신부 170 + 112/119 긴급 신고 [0057–0059] | 휴대폰 앱과 BLE 연결; 길게 누르기 또는 넘어짐 감지로 SOS; 앱에서 위치와 함께 한 번 눌러 전화/문자 | v1.0 (사용자가 통화 확인 — 웹 플랫폼 제약) |
| 마이크부 180, 음성통화 [0060–0061] | 휴대폰 블루투스 오디오를 통한 헤드셋 마이크 | v1.0 휴대폰 경유 |
| 팬, 탈착식 충전 배터리 [0028–0029] | 주머니/허리 가방의 USB-C 보조배터리 + 분리형 케이블; 자연 통풍구 | v1.0 |
| 에어커튼모듈 111 [0062–0064] | 개념 + 실험용 모듈 문서만(전력/소음) | 실험 단계 |
| 유로모듈 112 + 노즐모듈 113 [0065–0068] | 출력한 TPU 빗물 유로 조각 + 후방 노즐(수동식, 전원 불필요) | v1.0 선택 출력 |

---

## 3. 시스템 구조

```
                 ┌──────────────────────────── HELMET ────────────────────────────┐
                 │                                                                │
 Camera Module 3 ─┤► vision thread: capture → dehaze → detector → tracker → TTC ──┐│
 Wide (CSI)       │                          └► faces (on demand / low rate)      ││
                  │                          └► OCR (button-triggered)            ││
 TF-Luna FWD ─I2C─┤► reflex thread 50 Hz: head-height obstacle zones ────────────┤│
 TF-Luna DOWN ─I2C┤► reflex thread 50 Hz: drop-off / step detector ──────────────┤│
 MPU-6050 ────I2C─┤► imu thread 100 Hz: fall detection ──────────────────────────┤│
 3 buttons ──GPIO─┤► input thread: short / long / double press ──────────────────┤│
                  │                                                              ▼│
                  │                              EVENT BUS ──► hazard arbiter ─────┤
                  │                                               │                │
                  │           ┌───────────────────────────────────┼──────────┐     │
                  │           ▼                                   ▼          ▼     │
                  │   haptics (ULN2003 → 3 ERM)          audio (USB headset)  BLE link
                  │                                                              │ │
                  │  watchdog: heartbeats of every thread → FAULT events         │ │
                  └──────────────────────────────────────────────────────────────┼─┘
                                                                                 │ Nordic UART Service
                                                                   PHONE APP (PWA, Web Bluetooth)
                                                                   location · SOS · settings · log
```

그림 용어: vision thread = 영상 스레드(촬영 → 안개 제거 → 검출 → 추적 → TTC), faces = 얼굴 인식(요청 시 / 낮은 주기),
OCR = 글자 읽기(버튼 실행), reflex thread = 즉시 경고 스레드(머리 높이 장애물 구간 / 단차·계단 검출),
imu thread = IMU 스레드(넘어짐 감지), input thread = 입력 스레드(짧게 / 길게 / 두 번 누르기),
EVENT BUS = 이벤트 버스, hazard arbiter = 위험 판정기, haptics = 진동, audio = 음성,
watchdog = 감시기(모든 스레드의 heartbeat → FAULT 이벤트), PHONE APP = 휴대폰 앱(위치 · SOS · 설정 · 기록).

실행 환경: Raspberry Pi OS Bookworm 64비트, Python ≥ 3.11, 단일 프로세스, 하위 시스템마다 스레드 하나,
스레드 안전 이벤트 버스. 자동 재시작되는 systemd 서비스로 실행합니다.

---

## 4. 하드웨어 참조 설계

### 4.1 부품 목록 (참조 빌드)

| 참조 | 부품 | 수량 | 비고 / 전 세계 검색어 |
|---|---|---|---|
| H1 | 통풍구가 있는 인증 자전거/멀티스포츠 헬멧 | 1 | EN 1078 / CPSC / KC 마크. 사용자 머리에 맞는 크기. 챙(바이저) 없는 둥근 외피를 권장합니다. |
| U1 | Raspberry Pi 5, 4 GB (8 GB 권장) | 1 | 대안: Raspberry Pi 4 4 GB (프레임 속도 낮음) |
| U2 | Raspberry Pi Active Cooler (공식) | 1 | Pi 5에서는 필수 |
| U3 | microSD 32 GB A2 (또는 M.2 HAT를 통한 NVMe) | 1 | |
| C1 | Raspberry Pi Camera Module 3 **Wide** (IMX708, 120°) | 1 | |
| C2 | Pi 5 카메라 케이블 22핀→15핀, 300 mm | 1 | "Raspberry Pi 5 camera cable 300mm" |
| S1 | Benewake **TF-Luna** 라이다 (I2C 모드) — 전방 | 1 | 0.2–8 m, 시야각 2° |
| S2 | Benewake **TF-Luna** 라이다 (I2C 모드) — 하방 | 1 | |
| S3 | MPU-6050 (GY-521) IMU | 1 | 넘어짐 감지 |
| M1–M3 | 코인형 ERM 진동 모터 10 × 2.7 mm, 3 V, 리드선 포함 (1027 타입) | 3 | 왼쪽 / 가운데 / 오른쪽 |
| D1 | ULN2003 드라이버 보드 (28BYJ-48 키트에 포함된 것) | 1 | 모터 3개 구동 |
| B1–B3 | 12 × 12 mm 택트 버튼 모듈(3핀) 또는 12 mm 택트 스위치 + 듀폰선 | 3 | 캡은 서로 다른 모양으로 출력 |
| L1 | 3 mm LED + 330 Ω (또는 LED 모듈) | 1 | 비장애인 보조자를 위한 상태 표시 |
| A1 | 마이크 입력("라인 입력" 아님)이 제대로 되는 USB 오디오 어댑터 | 1 | Pi 5에는 3.5 mm 단자가 없음. 헤드셋 플러그와 맞출 것: 4극(TRRS, CTIA) 일체형 잭, 또는 헤드폰·마이크 분리형 잭 + 4극→3극 2분배 젠더 |
| A2 | 마이크가 있는 유선 오픈형 / 골전도 헤드셋 | 1 | 주변 소리를 막으면 안 됨 |
| P1 | USB-C 보조배터리, PD, 5 V 3 A 이상 출력, 10 000–20 000 mAh | 1 | 주머니 / 허리 가방에 휴대 |
| P2 | USB-C 케이블 1.5 m + 3 A 정격 자석식 분리형 USB-C 어댑터 | 1 | 분리형이라 목에 걸리지 않음 |
| W4 | USB-A 수 → 암 연장 케이블, 10–15 cm | 1 | Pi 5 USB 2.0 포트 → 보조 포드 안의 오디오 어댑터 |
| W1 | 듀폰 점퍼선 F-F 20 cm (40개 묶음), TF-Luna용 **6핀** 1.25 mm 리드선 (I2C 모드에는 5번 핀이 필요) | 1세트 | |
| W3 | 공유되는 SDA, SCL, 5 V, 3.3 V, GND 선을 위한 듀폰 1→N 암(F) 분배 케이블 (또는 2×8 암 헤더 분배기) | 1세트 | I2C 장치 3개와 여러 5 V 부하가 헤더 핀을 함께 씀. **Qwiic/STEMMA QT 허브는 쓰지 마세요**: 3.3 V 전용에 1 mm JST-SH 커넥터라서 5 V가 필요한 TF-Luna와 맞지 않음 |
| W2 | 20 mm 벨크로 스트랩 (200 mm), 3M 듀얼락 / VHB 패드 | 1세트 | |
| F1 | M2.5 × 6 나사 + 5 mm 스탠드오프(Pi), M2 × 5 나사(카메라, TF-Luna) | 1세트 | |
| G1 | 선택: u-blox NEO-M8N GPS (UART) | 0–1 | 휴대폰 없이 위치 확인 |
| R1 | 선택: 빗물 유로와 진동 패드용 TPU 필라멘트 | — | |

출력 부품: 단단한 부품은 PETG 또는 ASA(PLA는 여름 햇빛이나 뜨거운 차 안에서 물러집니다), 진동 패드,
새들, 빗물 유로는 TPU 95A. 스트랩 고정구는 PETG.

### 4.2 Raspberry Pi 5 핀 배치 (BCM 번호) — **기준값**

| 기능 | BCM GPIO | 헤더 핀 | 방향 | 비고 |
|---|---|---|---|---|
| I2C1 SDA | GPIO2 | 3 | bus | TF-Luna FWD 0x10, TF-Luna DOWN 0x11, MPU-6050 0x68 |
| I2C1 SCL | GPIO3 | 5 | bus | 400 kHz (`dtparam=i2c_arm=on,i2c_arm_baudrate=400000`) |
| 진동 LEFT | GPIO17 | 11 | out | → ULN2003 IN1 → M1 |
| 진동 CENTER | GPIO27 | 13 | out | → ULN2003 IN2 → M2 |
| 진동 RIGHT | GPIO22 | 15 | out | → ULN2003 IN3 → M3 |
| 버튼 B1 (원) | GPIO5 | 29 | in, pull-up | active-low |
| 버튼 B2 (세모) | GPIO6 | 31 | in, pull-up | active-low |
| 버튼 B3 (네모) | GPIO26 | 37 | in, pull-up | active-low |
| 상태 LED | GPIO16 | 36 | out | 330 Ω 경유 |
| GPS TX→Pi RX (선택) | GPIO15 | 10 | in | UART0, 9600 baud |
| GPS RX←Pi TX (선택) | GPIO14 | 8 | out | |
| 5 V | — | 2, 4 | power | ULN2003 +, TF-Luna ×2 (5 V). **버튼 모듈에는 절대 5 V를 공급하지 말 것** (GPIO에 5 V가 걸리면 Pi가 손상됨) |
| 3.3 V | — | 1, 17 | power | MPU-6050, 버튼 모듈 (**3.3 V 필수**; 모듈은 active-low여야 하며, 아니면 `buttons.active_high: true`로 설정 — 설정하지 않은 active-high 모듈은 계속 눌린 상태로 읽힘) |
| GND | — | 6, 9, 14, 20, 25, 30, 34, 39 | | 공통 접지 |

- **TF-Luna I2C 모드:** 커넥터 5번 핀(configuration)을 GND에 연결하면 I2C가 선택됩니다. TF-Luna의 신호는
  3.3 V와 호환되며, 전원은 5 V로 공급합니다. 하방 라이다의 주소는 한 번만 0x10에서 0x11로 바꿉니다:
  `python -m owsh.tools.tfluna_addr --from 0x10 --to 0x11`.
- **ULN2003에 연결한 ERM 모터:** 모터 +는 ULN2003 보드의 "+"(5 V)에, 모터 −는 OUT1..OUT3에 연결합니다.
  ULN2003 달링턴 전압 강하(약 1 V) 때문에 약 4 V가 걸리므로, 펌웨어는 PWM 듀티를 75 %로 제한해
  (`haptics.max_duty`) 3 V 모터에 과전압이 걸리지 않게 합니다.
- **카메라:** Pi 5의 CAM/DISP 0 커넥터.
- **오디오:** USB 오디오 어댑터는 USB 2.0 포트 아무 곳에나 꽂습니다(BLE 주변 2.4 GHz 잡음을 줄이기 위해 USB 3 포트는 비워 둡니다).
- **전력 예산:** Pi 5 부하 시 약 6.5 W, 주변 장치 약 1.5 W → 약 8 W. 3 A 전원에서는 USB 주변 장치 전류가
  600 mA로 제한되지만 충분합니다. 10 000 mAh ≈ 3.5 시간, 20 000 mAh ≈ 7 시간(보수적 추정).

### 4.3 기구 배치와 무게 예산

| 모듈 | 헬멧 위 위치 | 내용물 | 부착 방법 | 무게 예산 |
|---|---|---|---|---|
| 전방 센서 포드 | 앞쪽 윗부분, 이마 위 가운데 | C1 카메라(전방, 10° 아래로 기울임), S1 라이다(전방 수평), S2 라이다(수평에서 아래로 50° 기울임) | 앞쪽 통풍구로 통과시킨 20 mm 스트랩 2개(슬롯 21 × 3.2 mm) + 3 mm TPU 새들 위의 듀얼락 | ≤ 60 g (출력물 ≈ 40 g); 곡면 막대형 108 × 42 mm; 높이 ≤ 35 mm |
| 메인 케이스 | 정수리 뒤쪽 윗부분, 긴 쪽이 앞뒤 방향 | U1 + U2, S3 IMU, L1 LED 창 | 통풍구로 통과시킨 20 mm 스트랩 2개 + 3 mm TPU 새들 위의 듀얼락 | Pi 포함 ≤ 150 g (출력물 ≈ 52 g); 99 × 63 mm; 높이 ≤ 40 mm |
| 보조 포드(aux pod) | 뒷머리, 메인 케이스 아래 | D1 ULN2003 드라이버, A1 USB 오디오 어댑터(W4 연장 케이블 경유) | 스트랩 + 3 mm TPU 새들 위의 듀얼락 | ≤ 70 g (출력물 ≈ 30 g); 99 × 38 mm; 높이 ≤ 30 mm |
| 버튼 모듈 | 오른쪽 옆면, 귀 위, 아래 테두리 부근 | B1 앞, B2 가운데, B3 뒤 | 스트랩 고정구 + 듀얼락 | ≤ 25 g; 높이 ≈ 21 mm |
| 진동 패드 ×3 | 안쪽 쿠션 패드 위: 왼쪽 관자놀이, 이마 가운데, 오른쪽 관자놀이 | M1, M2, M3 | 헬멧 안쪽 쿠션 패드에 벨크로로 부착(EPS에 접착 금지) | 합계 ≤ 15 g |
| 빗물 유로 (선택) | 외피 아래 테두리를 따라, 앞 → 뒤 노즐 쪽으로 낮아짐 | TPU 조각 | 테두리에 끼우는 클립 + 스트랩 | ≤ 60 g |
| 케이블 | 스트랩 아래로 외피를 따라 | 출력 커버 안의 카메라 FPC, 듀폰선 묶음 | 케이블 클립 | ≤ 30 g |

빗물 유로를 제외한 추가 무게 합계 ≤ 380 g(추정 ≈ 330 g; 선택 사항인 빗물 유로는 ≈ 95 g을 더함 — 더 가벼운 유로는 로드맵 항목). 배터리는 헬멧에 달지 않습니다. 무게 중심은 헬멧 가운데 가까이 둡니다:
전방 포드와 메인 케이스가 서로 균형을 이룹니다.

### 4.4 주요 부품 치수 (캘리퍼스로 확인하십시오 — 모두 OpenSCAD 매개변수입니다)

| 부품 | 치수 | 장착 |
|---|---|---|
| Raspberry Pi 5 | PCB 85 × 56 × 1.6 mm; Active Cooler 포함 높이는 PCB 바닥에서 약 22 mm | M2.5 구멍 4개, 모서리에서 3.5 mm, 간격 58 × 49 mm |
| Camera Module 3 Wide | PCB 25 × 24 mm, 렌즈 포함 두께 약 12.4 mm | M2 구멍 4개, 간격 21 × 12.5 mm, 위쪽 구멍은 윗변에서 2 mm 아래; 렌즈 중심은 윗변에서 9.5 mm 아래 |
| TF-Luna | 35 × 21.25 × 13.5 mm, 5 g | 거치대 + M2 구멍 2개(확인 필요), 광학 창: 렌즈를 절대 가리지 말 것 |
| MPU-6050 GY-521 | 21 × 16 × 3 mm | 3 mm 구멍 2개 |
| ULN2003 보드 | 35 × 32 × 15 mm | 3 mm 구멍 4개(제품마다 다름) — 거치대 방식 |
| USB 오디오 어댑터 | 약 50 × 18 × 10 mm | 거치대 |
| 코인형 ERM 1027 | Ø 10 × 2.7 mm | TPU 패드의 홈 |
| 택트 스위치 12 × 12 | 12 × 12 × 7.3 mm (캡 축 별도) | 홈 |
| 헬멧 외피 (설계 범위) | 국부 반경 95–130 mm, 통풍구 ≥ 20 × 8 mm | TPU 새들이 곡면에 맞춰짐 |

---

## 5. 감지와 위험 판단 로직

### 5.1 즉시 경고 경로 — 전방 라이다 (머리 높이 장애물)

머리 높이 장애물(나뭇가지, 트럭 사이드미러, 간판, 열린 창문)은 흰지팡이로 알 수 없는 위험입니다.
50 Hz로 반복하며, 최근 3개 측정값의 중앙값을 씁니다. 유효하지 않은 측정값(신호 세기 < 100 또는 거리 = 0)은
"반사 없음"으로 봅니다.

| 구간 | 거리 | 진동 (CENTER 모터) | 음성 |
|---|---|---|---|
| Z3 알림 | 2.0 m ≥ d > 1.2 m | 2 Hz 짧은 진동, 40 % | 없음 |
| Z2 경고 | 1.2 m ≥ d > 0.6 m | 5 Hz 진동, 70 % | "Obstacle ahead"(앞에 장애물) 5초에 한 번 |
| Z1 임박 | d ≤ 0.6 m | 연속 100 % | "Stop"(멈추세요) (다른 음성을 끊고 우선) |

구간 사이 히스테리시스 0.1 m. 구간 경계값은 설정값입니다.
근거리 신호 끊김: TF-Luna는 0.2 m보다 가까우면 아무 값도 돌려주지 않습니다. 측정값이 Z1에 있다가 반사 없음으로 바뀌면
조용해지는 대신 Z1을 **0.5초 동안 유지**합니다.

### 5.2 즉시 경고 경로 — 하방 라이다 (낭떠러지와 단차)

기울기 θ = 수평에서 아래로 50°(설정 `dropoff.tilt_deg`). 평지를 걷는 동안 예상 거리 d₀는
분산이 낮은 측정값 3초 분량의 이동 중앙값으로 학습합니다(자동 보정, 1.2–3.5 m로 제한). **안전 규칙:** 더 긴 거리가
측정되는 동안 d₀를 자동으로 늘리지 않습니다(승강장 끝에 가만히 서 있을 때 선로 바닥을 "지면"으로 배우면 안 되기 때문).
더 짧은 거리가 안정적으로 유지되면 10초 뒤에 다시 학습합니다(예: 앉았을 때, 경사로).

- **DROP (내려가는 계단, 연석, 승강장 끝):** d > d₀ × 1.30 **또는** 반사 없음이 120 ms 이상 지속
  → P1 IMMINENT, 모든 모터가 긴 진동 2회, 음성 "Step down ahead"(앞에 내려가는 턱) / "Drop ahead"(앞에 추락 위험).
- **STEP UP (올라가는 단차 / 낮은 장애물):** d < d₀ × 0.70이 120 ms 이상 지속 → P2 WARNING, 가운데 모터
  짧은 진동 3회, 음성 "Step up ahead"(앞에 올라가는 턱).
- 종류별 재알림 대기 3초. 아주 어둡거나 젖은 바닥에서 반사가 없으면 DROP으로 보고합니다. 낭떠러지를 놓치는 것이
  오경보보다 더 나쁘기 때문입니다. 사용자는 민감도를 낮출 수 있습니다(`dropoff.no_return_is_drop: false`).

### 5.3 영상 경로

- 1280 × 720으로 촬영 → 검출기 크기로 축소. Pi 5에서 목표 ≥ 8 FPS.
- 전처리: 안개/비/저조도에 대비한 휘도 CLAHE 선택 적용(`vision.dehaze: auto|on|off`).
- 검출기: **NanoDet-Plus-m 416** (OpenCV Zoo `object_detection_nanodet_2022nov.onnx`,
  Apache-2.0), `cv2.dnn`으로 실행. 호환되는 ONNX 모델이면 무엇이든 설정할 수 있습니다.
- 관심 클래스(COCO): person, bicycle, car, motorcycle, bus, truck, dog, horse,
  bench, fire hydrant, stop sign, parking meter, traffic light, chair, potted plant, suitcase.
  "움직이는 것(movers)" = person, bicycle, car, motorcycle, bus, truck, dog, horse.
- 추적기: IoU 탐욕(greedy) 추적기, 검출이 없어도 트랙을 0.7초 유지.
- 방향: 카메라 수평 화각(Camera Module 3 Wide: 102°)을 이용해 경계 상자 중심에서 수평 각도를 구합니다.
  LEFT < −15° ≤ CENTER ≤ +15° < RIGHT.
- 충돌 예상 시간(TTC): TTC = Δt / (s − 1), s = 0.4초 이상 구간의 경계 상자 높이 비율(평활화).
- 경고:
  - **APPROACH P1:** TTC < 1.5 s이고 경계 상자 높이가 화면의 20 %를 넘는 움직이는 것.
  - **APPROACH P2:** TTC < 3.0 s(차량: < 4.0 s)이고 경계 상자 높이가 화면의 10 %를 넘는 움직이는 것.
  - 조건이 **처리된 프레임 2장 연속**으로 성립해야 합니다(경계 상자 떨림 억제).
- 같은 단계는 트랙별 재알림 대기 5초; 더 높은 단계로 올라가면 대기를 무시합니다.
- 검출기 입력 색상 순서는 설정할 수 있습니다(`color_order: rgb|bgr`, 기본값은 OpenCV Zoo 데모와 같은 rgb).
- **장면 설명 (버튼):** 가까운 순서(경계 상자 높이)로 최대 5개 물체를 클래스와 방향별로 묶어 말합니다:
  "2 people ahead, bicycle on the right"(앞에 사람 2명, 오른쪽에 자전거).

### 5.4 얼굴

- YuNet 2023mar 검출기 + SFace 2021dec 인식기 (OpenCV Zoo, MIT / Apache-2.0).
- 사람이 검출되었을 때 가장 최근 프레임에서 ≤ 2 Hz로 실행합니다.
- 등록 데이터베이스: `data/faces/<name>/{*.jpg}` + `data/faces/index.json`, `tag: friend|avoid`.
  등록 명령: `python -m owsh.tools.enroll_face --name "Mina" --tag friend --camera 0` (또는 이미지로 등록).
- 일치 판단: 코사인 유사도 ≥ 0.363 (SFace 권장 임계값). 마스크 대응: YuNet 신뢰도 ≥ 0.6이면 얼굴 일부만
  보여도 받아들입니다. 더 낮은 유사도 임계값도 설정할 수 있습니다.
- friend → P3 INFO "Mina is ahead on the left"(왼쪽 앞에 민아 님), 해당 쪽 짧은 진동 2회,
  사람별 재알림 대기 60초.
- avoid → 음성과 함께 P2 WARNING, 재알림 대기 60초.
- 개인정보: 얼굴 특징값(embedding)과 사진은 헬멧 밖으로 나가지 않습니다. BLE로는 이름만 보냅니다.

### 5.5 OCR (버튼 실행)

- 설치되어 있으면 `rapidocr_onnxruntime`(Apache-2.0) 백엔드를 사용하며, 언어는 설정에서 정합니다. 설치되어 있지 않으면
  음성 "Text reading is not installed"(문자 읽기 기능이 설치되어 있지 않습니다).
- 새로 찍은 프레임의 가운데 70 % 영역을 읽고, 줄을 위에서 아래 순서로 정리해 최대 200자까지 말합니다.
  B1을 길게 누르면 마지막으로 말한 메시지를 반복합니다.
- 위험 키워드(언어별 설정 목록, 예: "위험", "공사", "DANGER", "CAUTION", "WET FLOOR")가 들어간 표지판은
  앞에 "Warning sign:"(경고 표지:)을 붙여 읽습니다.

### 5.6 넘어짐 감지 (IMU)

- 자유낙하 |a| < 0.35 g가 80 ms 이상 → 1초 안에 충격 |a| > 2.5 g → 이후 2초간 움직임 적음
  (|a|가 1 ± 0.15 g 이내) → FALL → SOS 카운트다운(§7.3).

### 5.7 감시기 (watchdog)

각 스레드는 heartbeat를 보냅니다. 시간 제한: 카메라 프레임 2 s, 라이다 0.5 s, IMU 1 s,
오디오 백엔드 초기화 실패는 즉시.

**카메라 가림 / 보이지 않는 카메라:** 프레임은 계속 들어오지만 렌즈가 가려졌거나(진흙, 빗물막,
스티커, 모자) 완전히 어두운 경우입니다. 평균 휘도 < 12 (0–255) **이고** 휘도 표준편차 < 6이
3초 이상 지속되거나, **또는** 픽셀의 97 % 이상이 12보다 어두운 상태가 3초 이상 지속되면(작은 아이콘이 있는 개인정보
보호 셔터 화면) FAULT `camera_blocked`를 냅니다(음성: "Camera is covered or too dark"(카메라가 가려졌거나 너무 어둡습니다.)).
라플라시안 분산(선명도)이 5초 이상 < 5로 유지될 때(렌즈 번짐)도 같은 FAULT를 냅니다. 라이다 즉시 경고 경로는
계속 동작하며 음성으로 알립니다("Distance sensors still active"(거리 센서는 계속 작동합니다.)).

**전원과 온도 (Pi):** 펌웨어 `get_throttled` 플래그를 5초마다 읽습니다. 저전압(bit 0)이 10초 이상 계속되면
→ P2 "Power is low. Charge the battery soon."(전원이 부족합니다. 곧 배터리를 충전하세요.) (최대 5분에 한 번).
CPU ≥ 80 °C → P2 "Helmet is overheating."(헬멧이 과열되었습니다.) (최대 5분에 한 번, 75 °C 아래로 내려가면 다시 활성화).
고장 → FAULT 이벤트(구성요소 id). **안전과 관련된 구성요소**(카메라, 라이다, 진동, IMU)의 FAULT는 지속되는 동안
10초마다 반복합니다(P0). 안전과 무관한 구성요소(얼굴, OCR, BLE, 설정)는 P2로 한 번만 알립니다.
복구 → 음성 "<component> recovered"(<구성요소> 복구됨.).

---

## 6. 진동 언어 (모터 L = 왼쪽 관자놀이, C = 이마, R = 오른쪽 관자놀이)

### 6.1 우선순위

| 단계 | 이름 | 예 | 우선하는 대상 |
|---|---|---|---|
| P0 | CRITICAL (위급) | SOS 카운트다운, 시스템 FAULT | 전부 |
| P1 | IMMINENT (임박) | Z1 장애물, DROP, APPROACH P1 | P2–P4 |
| P2 | WARNING (경고) | Z2 장애물, STEP UP, APPROACH P2, 기피 대상 | P3–P4 |
| P3 | INFO (정보) | Z3 알림, 지인 얼굴, OCR 결과, 장면 설명 | P4 |
| P4 | STATUS (상태) | 준비 완료, 버튼 확인 진동, 음소거 전환 | — |

진동 믹서는 활성화된 모든 패턴을 모터별로 계산하고, 10 ms 틱마다 모터별 **최댓값** 세기를 사용합니다
(연속되는 즉시 경고 패턴과 한 번만 울리는 패턴이 함께 존재할 수 있음). 음성은 엄격한 선점 방식입니다(§7.1).

### 6.2 패턴 표 (기준값)

| 패턴 id | 모터 | 타이밍 | 의미 |
|---|---|---|---|
| `tick` | C | 40 ms @ 60 % | 버튼 입력 확인 / "작동 중" |
| `zone3` | C | 반복: 60 ms 켬 / 440 ms 끔 @ 40 % | 장애물 1.2–2.0 m |
| `zone2` | C | 반복: 80 ms 켬 / 120 ms 끔 @ 70 % | 장애물 0.6–1.2 m |
| `zone1` | C | 연속 @ 100 % | 장애물 ≤ 0.6 m |
| `drop` | L+C+R | 2 × (400 ms 켬 / 150 ms 끔) @ 100 % | 낭떠러지 / 내려가는 계단 |
| `step_up` | C | 3 × (100 ms 켬 / 100 ms 끔) @ 80 % | 올라가는 단차 / 낮은 장애물 |
| `approach_left` / `approach_right` / `approach_center` | L / R / C | 3 × (150 ms 켬 / 80 ms 끔) @ 100 % (P1) 또는 70 % (P2) | 그쪽에서 움직이는 물체가 다가옴 |
| `person_friend_<side>` | 해당 쪽 | 2 × (80 ms 켬 / 120 ms 끔) @ 60 % | 등록된 지인 |
| `person_avoid_<side>` | 해당 쪽 | 4 × (60 ms 켬 / 60 ms 끔) @ 90 % | 등록된 기피 대상 |
| `turn_left` / `turn_right` | L / R | 250 ms 켬 / 750 ms 끔, 활성 동안 반복 @ 70 % | 방향 안내(내비게이션, 로드맵) |
| `count_n` | C | n × (120 ms 켬 / 280 ms 끔) @ 70 %, n ≤ 10 | 숫자(예: 층수) [0044] |
| `sos_countdown` | L+C+R | 1 Hz 200 ms @ 100 %, 10초간 | SOS를 보낼 예정 |
| `fault` | C | 3 × (50 ms 켬 / 50 ms 끔) @ 100 %, 10초마다 | 하위 시스템 고장 — 침묵을 믿지 말 것 |
| `ready` | L → C → R | 각 100 ms, 순서대로 @ 60 % | 부팅 완료 |

---

## 7. 음성, 버튼, SOS

### 7.1 음성

- 백엔드 순서: `piper` CLI(설정한 경우, 자연스러운 음성), `espeak-ng`(Pi 기본, ko/en 지원),
  `pyttsx3`(데스크톱 개발용). 고정 문구는 미리 만든 WAV 파일을 `data/cache/tts/`에 캐시합니다.
- 대기열: 우선순위가 더 높은 메시지는 현재 메시지를 끊고, 같거나 낮은 메시지는 기다립니다.
  대기 중인 P1/P2 메시지가 2초보다 오래되면 버립니다. 대기열은 최대 3개입니다.
- 음소거(B3 두 번 누르기)는 P3–P4 음성만 끕니다. P0–P2는 항상 말합니다. **버튼으로 요청한 것에 대한 대답
  (글자 읽기, 장면 설명, 상태 안내, 여기가 어디인지, 누가 있는지)은 음소거 중에도 말합니다.**
- 모든 문구는 메시지 id를 키로 하여 `owsh/i18n/<lang>.json`에 있으며, `{placeholders}`를 쓸 수 있습니다.

### 7.2 버튼 (B1 앞 ○ 원, B2 가운데 △ 세모, B3 뒤 □ 네모)

| 버튼 | 짧게 누르기 (< 0.8 s) | 길게 누르기 (≥ 1.5 s) | 두 번 누르기 (간격 < 0.4 s) |
|---|---|---|---|
| B1 ○ | 글자 읽기 (OCR) | 마지막 메시지 반복 | — |
| B2 △ | 장면 설명 | 여기가 어디인지 (휴대폰 위치) | 누가 있는지 (얼굴) |
| B3 □ | 상태 안내 | 3초 누르고 있기: SOS 카운트다운 | 음성 음소거 전환 (P3–P4) |

타이밍: 0.8초에서 길게 누르기 기준 사이의 누르기는 무시합니다. B3의 길게 누르기는 3초이며, 누르고 있는 동안 실행됩니다.
받아들인 모든 버튼 입력에는 즉시 `tick`을 줍니다. SOS 카운트다운 중에는 아무 버튼이나 누르면 취소됩니다.

**안전하게 끄기:** **B1 ○ + B3 □를 함께 5초 누르고 있기**(두 버튼을 1초 안쪽으로 함께 누름) → 음성
"Shutting down"(전원을 끕니다.) + `ready` 패턴을 거꾸로(R→C→L) → 3초 뒤 전원 끔. 두 버튼을 함께 누르고 있는 동안에는
B3의 SOS 길게 누르기와 B1의 길게 누르기가 막히며, 둘 중 하나라도 일찍 떼면 취소됩니다.

### 7.3 SOS

1. 시작 조건: B3를 3초 누르고 있기, 또는 FALL.
2. 10초 카운트다운: `sos_countdown` + 음성 "Emergency alert in 10 seconds. Press any button to cancel."
   (10초 뒤 긴급 신고를 보냅니다. 취소하려면 아무 버튼이나 누르세요.)
3. 취소하지 않으면: BLE로 `sos`를 보내고(휴대폰이 확인(ack)할 때까지 5초마다 반복), 음성 "Sending emergency alert"
   (휴대폰으로 긴급 신고를 보내는 중입니다.). "Emergency alert sent"(긴급 신고를 보냈습니다.)는 휴대폰의 `ack`를 받은 뒤에만 말합니다.
4. 휴대폰 앱: 큰 경보음 + 진동, 위치 표시, 큰 버튼 "긴급 전화 걸기"
   (국가별 설정: 112 / 119 / 911 …)와 "보호자에게 문자 보내기"(지도 링크가 미리 채워짐).
   웹 플랫폼에서는 사용자(또는 주변 사람)가 통화/문자를 확인해야 합니다. 네이티브 앱은 자동화할 수 있습니다(로드맵).
5. 휴대폰이 연결되어 있지 않으면: 10초마다 음성 "Phone not connected"(휴대폰이 연결되지 않았습니다), 주변 사람이 알아차리도록
   `sos_countdown` 패턴을 60초간 계속합니다(LED 빠르게 깜빡임). 아무 버튼이나 누르면 취소됩니다.

---

## 8. 헬멧 ↔ 휴대폰 통신 규약 (BLE, Nordic UART Service)

- 서비스 `6E400001-B5A3-F393-E0A9-E50E24DCCA9E`
- RX (휴대폰 → 헬멧, write / write-without-response) `6E400002-B5A3-F393-E0A9-E50E24DCCA9E`
- TX (헬멧 → 휴대폰, notify) `6E400003-B5A3-F393-E0A9-E50E24DCCA9E`
- 장치 이름: `OWSH-XXXX` (블루투스 MAC 주소의 마지막 16진수 4자리).
- 프레이밍: `\n`으로 끝나는 UTF-8 JSON 객체. 협상된 MTU − 3보다 긴 메시지는 여러 조각으로 나누어 보내고,
  받는 쪽은 `\n`이 올 때까지 모아 둡니다. 메시지 최대 1024바이트.
- 모든 메시지에는 `"t"`(종류)와 `"v": 1`(규약 버전)이 있습니다. 헬멧이 보내는 메시지에는 `"ts"`(유닉스 ms)가 있습니다.

### 8.1 헬멧 → 휴대폰

| t | 필드 | 보내는 때 |
|---|---|---|
| `hello` | `fw`, `lang`, `features` [list] | 연결 시 |
| `status` | `uptime_s`, `cpu_temp_c`, `fps`, `faults` [list], `muted` | 10초마다, 그리고 변경 시 |
| `alert` | `id`, `level` 0–4, `kind` (`obstacle`,`drop`,`step_up`,`approach`,`face`,`sign`,`fault`), `dir` (`left`,`center`,`right`,`all`), `dist_m`?, `label`?, `text` | P3 이상의 음성/진동 경고마다 |
| `speech` | `text`, `level` | 말한 모든 내용 (앱의 접근성 기록용) |
| `sos` | `id`, `reason` (`button`,`fall`), `state` (`countdown`,`sent`,`cancelled`) | SOS 진행 |
| `need_location` | — | B2 길게 누르기 |
| `pong` | `id` | ping에 대한 응답 |

### 8.2 휴대폰 → 헬멧

| t | 필드 | 효과 |
|---|---|---|
| `loc` | `lat`, `lon`, `acc_m`, `addr`? | 최신 위치; `addr`가 있으면 "여기가 어디인지"에서 말함 |
| `ack` | `id` | `sos` 수신 확인 |
| `say` | `text`, `level` (기본 3) | 헬멧을 통해 텍스트를 말함 |
| `cfg` | `lang`?, `muted`?, `volume`? (0–100), `dropoff_sensitivity`? (`low`,`normal`,`high`) | 실행 중 설정 변경 |
| `ping` | `id` | 연결 확인 |

알 수 없는 종류는 무시합니다(향후 호환성).

`status`에는 `undervoltage`와 `throttled`(불리언, 알 수 없으면 생략)도 들어 있습니다.

### 8.3 보안
- 헬멧은 **암호화되고 본딩된(bonded)** BLE 연결을 요구합니다: RX는 `encrypt-write`, TX는
  `encrypt-read` + `encrypt-notify`입니다(Just Works 페어링 — 헬멧에는 화면이 없음). 처음 연결할 때 휴대폰 OS가
  표준 페어링 대화상자를 보여 줍니다.
- `ble.bonded_only: true`(기본값): 본딩되지 않은 장치의 메시지는 버립니다. 본딩된 휴대폰이 없는 동안에는 페어링이
  열려 있고, 그 뒤에는 부팅할 때마다 120초 동안만 열립니다. 새 페어링은 음성으로 알립니다.
- 안전을 낮추는 `cfg` 변경은 항상 P2로 소리 내어 확인합니다(음소거 중에도 들림): 음소거 켜기,
  낙차 감지 민감도 low, 음량 30 % 미만 설정.
- 휴대폰의 `say`는 P2로 제한되고(P0/P1 음성을 절대 끊지 못함) 3초에 1개로 속도가 제한됩니다.

---

## 9. 소프트웨어 구성과 인터페이스

```
firmware/
  pyproject.toml            # package "owsh"; extras: pi, ocr, ble, dev
  config/default.yaml       # all thresholds from this spec
  owsh/__main__.py          # python -m owsh [--config path] [--sim] [--video file] [--no-window]
  owsh/app.py               # wires threads, bus, arbiter, watchdog
  owsh/config.py            # dataclass config + YAML loader + validation
  owsh/events.py            # Event types, Level enum (P0..P4)
  owsh/bus.py               # thread-safe publish/subscribe
  owsh/arbiter.py           # hazard → haptic pattern + speech decisions, cooldowns
  owsh/i18n/__init__.py, ko.json, en.json
  owsh/vision/camera.py     # Picamera2 | OpenCV index | video file
  owsh/vision/preprocess.py # dehaze/CLAHE
  owsh/vision/detector.py   # NanoDet-Plus ONNX (cv2.dnn), class filter
  owsh/vision/tracker.py    # IoU tracker + TTC
  owsh/vision/describe.py   # scene description text
  owsh/vision/faces.py      # YuNet + SFace + DB
  owsh/vision/ocr.py        # RapidOCR optional
  owsh/sensors/tfluna.py    # I2C driver (smbus2) + simulated
  owsh/sensors/reflex.py    # zone logic (5.1) + drop-off logic (5.2)
  owsh/sensors/imu.py       # MPU-6050 driver + fall detector (5.6)
  owsh/output/haptics.py    # pattern engine + mixer; backends: gpiozero PWM | sim
  owsh/output/audio.py      # speech queue; piper | espeak-ng | pyttsx3 | print
  owsh/input/buttons.py     # gpiozero | keyboard (sim)
  owsh/link/ble.py          # NUS GATT server via "bless"; no-op when unavailable
  owsh/link/protocol.py     # message encode/decode/chunking (pure, tested)
  owsh/watchdog.py
  owsh/sim/dashboard.py     # desktop debug window: video, boxes, motor bars, sim LiDAR sliders
  owsh/tools/download_models.py, enroll_face.py, tfluna_addr.py, bench.py
  tests/                    # pytest: arbiter, reflex, dropoff, tracker/TTC, haptic mixer, protocol, buttons, fall
  scripts/setup_pi.sh       # apt + venv + config.txt I2C + systemd
  systemd/owsh.service
hardware/
  openscad/lib/*.scad       # common: rounded boxes, saddle, strap slots, parameters
  openscad/*.scad           # one file per printable part
  stl/                      # rendered outputs (committed for non-CAD users)
  renders/                  # PNG previews
  wiring/                   # wiring diagram (SVG) + pin table
app/                        # PWA: index.html, app.js, protocol.js, i18n/, sw.js, manifest
docs/en, docs/ko            # guides
```

위 트리의 파일 이름과 주석은 코드와 맞추기 위해 영어 그대로 둡니다. 주요 설명:
`config/default.yaml` = 이 설계서의 모든 임계값, `app.py` = 스레드·버스·판정기·감시기 연결,
`arbiter.py` = 위험 → 진동 패턴·음성 결정과 재알림 대기, `reflex.py` = 구간 로직(5.1) + 단차 로직(5.2),
`protocol.py` = 메시지 인코딩/디코딩/분할(순수 함수, 테스트됨), `sim/dashboard.py` = 데스크톱 디버그 창
(영상, 상자, 모터 막대, 가상 라이다 슬라이더), `tests/` = pytest(판정기, 즉시 경고, 단차, 추적/TTC, 진동 믹서,
통신 규약, 버튼, 넘어짐), `scripts/setup_pi.sh` = apt + venv + config.txt I2C + systemd,
`stl/` = 렌더링 결과(CAD를 쓰지 않는 사람을 위해 저장소에 포함), `renders/` = PNG 미리보기,
`wiring/` = 배선도(SVG) + 핀 표, `app/` = PWA, `docs/en, docs/ko` = 가이드.

**시뮬레이션 모드 (`--sim`)**는 웹캠이나 동영상 파일이 있는 어느 PC에서나 실행됩니다. 라이다와 IMU는
대시보드의 슬라이더/키로 흉내 내고, 진동은 막대로 그리고 출력하며, 버튼은 키로 대신합니다
(`1`/`2`/`3` 짧게, `Shift+1..3` 또는 `q`/`w`/`e` 길게, `a`/`s`/`d` 두 번), 음성은 pyttsx3를 씁니다.

---

## 10. 출력 부품 목록 (OpenSCAD, 매개변수 방식)

| 파일 | 부품 | 재료 | 수량 | 비고 |
|---|---|---|---|---|
| `front_pod_base.scad` | 카메라 칸(10° 아래), 전방 라이다 칸, 하방 라이다 칸(50°)이 있는 전방 포드 몸체 | PETG/ASA | 1 | 렌즈 위 빗물 턱, 스트랩 슬롯 21 × 3 mm |
| `front_pod_cover.scad` | FPC와 케이블 출구가 있는 뒤 덮개 | PETG/ASA | 1 | |
| `main_case_base.scad` | 스탠드오프, IMU·ULN2003·오디오 어댑터 칸, 통풍구가 있는 Pi 5 케이스 바닥 | PETG/ASA | 1 | USB-C 전원과 쿨러 배기 구멍은 아래/뒤를 향함 |
| `main_case_lid.scad` | LED 도광 구멍과 물받이 턱이 있는 뚜껑 | PETG/ASA | 1 | |
| `aux_pod_base.scad` | 보조 포드 바닥: ULN2003과 USB 오디오 어댑터 거치대 | PETG/ASA | 1 | 곡면 바닥면 |
| `aux_pod_lid.scad` | 보조 포드 뚜껑 | PETG/ASA | 1 | |
| `saddle_pad.scad` | 포드/케이스 아래의 곡면 TPU 새들(곡률 매개변수) | TPU | 2 | |
| `button_module.scad` | 12 mm 스위치 3개용 버튼 하우징 | PETG | 1 | |
| `button_caps.scad` | 볼록한 촉각 테두리가 있는 ○ △ □ 캡 | PETG | 1세트 | |
| `haptic_pad.scad` | 벨크로 홈이 있는 코인 모터 패드 | TPU | 3 | |
| `strap_anchor.scad` | 20 mm 스트랩 고정구 / 버클 | PETG | 4 | |
| `cable_clip.scad` | FPC 커버와 듀폰선 묶음용 케이블 클립 | PETG | 6 | |
| `fpc_cover.scad` | 카메라 케이블 커버 채널 | PETG | 1 | |
| `rain_gutter_segment.scad` | 유로 조각(앞이 높고 → 뒤가 낮음), 테두리에 끼우는 방식 | TPU | 4 | 특허 112 |
| `rain_nozzle_rear.scad` | 양쪽을 모으는 후방 노즐 | TPU | 1 | 특허 113 |
| `assembly_preview.scad` | 헬멧 형상 위의 전체 조립 모습(출력하지 않음) | — | — | 렌더링용 |

곡면 바닥면 부품(전방 포드, 메인 케이스, 보조 포드)은 곡면 아래에 빌드 플레이트에서 올라오는 슬라이서 서포트가 필요합니다.
새들/포드의 곡률은 출력할 때 `helmet_radius` / `helmet_radius_long`으로 정해지므로 — 먼저 헬멧을 재십시오.

출력 설정(참고값): 레이어 0.2 mm, 벽 4겹, 채움 25 % 자이로이드(단단한 부품), TPU는 벽 100 %
(3겹) 채움 15 %, 서포트는 곡면 바닥면 아래에만(그 밖의 오버행 ≤ 45°), PETG 240 °C / 80 °C.

---

## 11. 검증 계획 (요약)

| ID | 시험 | 합격 기준 |
|---|---|---|
| T1 | 단위 테스트 `pytest` | 모두 통과 |
| T2 | 즉시 경고 지연 시간 라이다 → 모터 | ≤ 60 ms (로그 타임스탬프) |
| T3 | Pi 5에서 영상 FPS | NanoDet 416 기준 ≥ 8 FPS |
| T4 | 머리 높이 장애물 (1.8 m 높이의 나뭇가지 모형) | 1.2 m 전에 Z2, 0.6 m 전에 Z1, 20/20 시행 |
| T5 | 내려가는 계단 (계단 5곳, 낮/밤) | 첫 계단 끝 전에 DROP 19/20 |
| T6 | 다가오는 자전거 / 사람 | TTC ≥ 1.5 s일 때 APPROACH 경고, 18/20 |
| T7 | 오경보율, 30분 도심 보행 | P1 오경보 ≤ 2회 / 10분 |
| T8 | 고장 주입: 카메라 / 라이다 분리; 렌즈 가리기 | 분리 시 3초 안에 FAULT(프레임 시간 제한 2초), 렌즈를 가렸을 때 4초 안에, 라이다는 1초 안에 |
| T9 | SOS: B3 누르고 있기, 매트리스 위 넘어짐 | 카운트다운, 휴대폰이 `sos` 수신 |
| T10 | 20 000 mAh 배터리 연속 사용 | ≥ 6 시간 |
| T11 | 충격: 추가 모듈이 떨어져 나가거나 파고들지 않음 | 헤드폼에 씌운 헬멧을 1 m에서 떨어뜨린 후 육안 확인; 개조한 헬멧을 판매용으로 인증 시험할 때는 반드시 공인 시험기관을 거칠 것 |
| T12 | 시각장애인 보행자 + 보행지도사와 함께하는 사용자 시험 | 정성 보고서, 안전사고 = 0 |

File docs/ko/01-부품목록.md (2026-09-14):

# 01 · 부품 목록

> 오픈 보행 안전 헬멧 프로젝트 문서 · CC BY 4.0 라이선스 · © 2026 씨엘소프트랩(CLSOFTLAB), 이일국 박사

이 문서는 기본 구성(레퍼런스 빌드)에 필요한 부품을 모두 정리한 것입니다. 부품마다 대략적인 가격과
찾아볼 만한 구입처도 함께 적었습니다. 기준이 되는 부품 목록은 [시스템 설계서](00-시스템설계서.md)의
§4.1 부품 목록(참조 빌드)입니다. 이 문서와 설계서 내용이 서로 다르면 설계서를 따릅니다. 이슈를 열어
알려 주시면 바로잡겠습니다.

> **주문하실 때는** [구매 가이드](10-구매가이드.md)를 보세요. 디바이스마트·엘레파츠 실제 상품 링크, 모델명, 잘못 사기 쉬운 부품을 장바구니 단위로 정리했습니다.

프로그램에서 읽기 쉬운 형식은 [`../bom.csv`](../bom.csv)에 있습니다 (공식·해외·국내 구매 링크 열 포함). 부품, 사양, 검색 키워드,
가격 범위, 판매처 종류 열이 들어 있습니다.

> **가격 안내.** 모든 가격은 **2026년 9월 기준 대략적인 가격이며, 미국 달러(USD) 범위로 표시**했습니다.
> 배송비, 관세, 부가가치세는 포함하지 않았습니다. 가격은 자주 바뀝니다. 특히 라즈베리파이 보드와
> 메모리가 그렇습니다. 사기 전에 적어도 두 곳 이상 비교해 보세요.

## 목차

- [구매 전 확인할 것](#구매-전-확인할-것)
- [기본 구성 부품](#기본-구성-부품)
- [선택 부품](#선택-부품)
- [출력 부품과 필라멘트](#출력-부품과-필라멘트)
- [총비용](#총비용)
- [저가형 구성](#저가형-구성)
- [구입처](#구입처)
- [필요한 공구](#필요한-공구)

## 구매 전 확인할 것

- **헬멧은 인증받은 새 제품이어야 합니다.** EN 1078(유럽), CPSC 1203(미국), AS/NZS 2063(호주·뉴질랜드),
  KC(한국) 또는 해당 국가의 동등한 인증을 확인하세요. 통풍구가 있고 챙(바이저)이 없는 둥근 헬멧 외피(셸)를
  고르세요. 실제로 쓸 사람의 머리에 맞춰 고릅니다. 사고를 한 번이라도 겪은 헬멧은 절대 쓰지 마세요.
- **TF-Luna는 6핀 케이블이 포함된 제품으로 사세요.** 6핀 1.25 mm(GH) 커넥터를 씁니다. 5번 핀으로
  I2C 모드를 선택하므로 4핀 케이블로는 부족합니다.
- **코인 모터는 커넥터가 달렸거나 선이 긴 제품으로 사세요.** 기본 구성은 납땜을 하지 않습니다.
- **버튼 모듈은 3.3 V에서 동작하고 액티브 로우(active-low) 방식이어야 합니다.** 가장 간단한 선택은
  택트 스위치 단품입니다. [02 · 배선 가이드](02-배선가이드.md)의 6단계 버튼(B1–B3) 부분을 참고하세요.
- **출처를 알 수 없는 microSD 카드는 피하세요.** 카드 고장은 헬멧이 작동을 멈추는 가장 흔한 원인 가운데
  하나입니다.

## 기본 구성 부품

참조 기호(Ref)는 설계서, 배선 가이드, 펌웨어와 같습니다.

| 참조 | 부품 | 수량 | 핵심 사양 | 검색 키워드 | 단가 (USD, 대략) |
|---|---|---|---|---|---|
| H1 | 통풍구가 있는 인증 자전거/멀티스포츠 헬멧 | 1 | EN 1078 / CPSC / AS/NZS / KC; 통풍구 ≥ 20 × 8 mm | `certified bicycle helmet EN 1078 vents` | 30–80 |
| U1 | 라즈베리파이 5, 4 GB (8 GB 권장) | 1 | 가격 하단은 4 GB, 상단은 8 GB | `Raspberry Pi 5 8GB` | 60–120 |
| U2 | 라즈베리파이 액티브 쿨러 (공식) | 1 | Pi 5에는 필수 | `Raspberry Pi 5 Active Cooler` | 5–8 |
| U3 | microSD 32 GB A2 | 1 | 믿을 수 있는 브랜드 (또는 M.2 HAT으로 NVMe 사용) | `microSD 32GB A2` | 8–15 |
| C1 | 라즈베리파이 카메라 모듈 3 **Wide** | 1 | IMX708, 대각 120° / 수평 102° | `Raspberry Pi Camera Module 3 Wide` | 35–45 |
| C2 | Pi 5용 카메라 케이블 22핀 → 15핀, 300 mm | 1 | FPC | `Raspberry Pi 5 camera cable 300mm` | 2–5 |
| S1 | Benewake **TF-Luna** 라이다, 전방용 | 1 | 0.2–8 m, 시야각 2°, I2C 모드 | `Benewake TF-Luna LiDAR` | 18–35 |
| S2 | Benewake **TF-Luna** 라이다, 아래 보기용 | 1 | S1과 같음, 주소를 0x11로 변경 | `Benewake TF-Luna LiDAR` | 18–35 |
| S3 | MPU-6050 (GY-521) IMU | 1 | I2C 0x68, 넘어짐 감지 | `GY-521 MPU-6050` | 2–5 |
| M1–M3 | 코인형 ERM 진동 모터 1027, 3 V, 리드선 포함 | 3 | 10 × 2.7 mm; 왼쪽 / 가운데 / 오른쪽 | `1027 coin vibration motor 3V` | 개당 0.5–2 |
| D1 | ULN2003 드라이버 보드 (28BYJ-48 키트 구성품) | 1 | 모터 3개 구동; 보조 포드(aux pod)에 들어감 | `ULN2003 driver board 28BYJ-48` | 1–3 |
| B1–B3 | 12 × 12 mm 택트 스위치 (또는 3핀 버튼 모듈, **3.3 V, 액티브 로우**) | 3 | 누르는 동안만 켜지는 방식 | `12x12mm tactile switch` | 개당 0.3–1.5 |
| L1 | 3 mm LED + 330 Ω 저항 (또는 LED 모듈) | 1 | 곁에 있는 비장애인 도우미가 눈으로 확인하는 상태 표시 | `3mm LED module` | 0.2–1 |
| A1 | 마이크 입력이 제대로 되는 USB 오디오 어댑터 | 1 | Pi 5에는 3.5 mm 단자가 없음; 보조 포드에 들어감. 헤드셋 플러그와 맞춰야 함 (4극 일체형 잭, 또는 분리형 잭 + 4극→3극 분배 젠더) — [구매 가이드](10-구매가이드.md) 참고 | `USB audio adapter headphone mic` | 5–15 |
| A2 | 오픈형 / 골전도 유선 헤드셋, 마이크 포함 | 1 | 귀를 막지 않아야 함 | `wired bone conduction headphones mic` | 15–60 |
| P1 | USB-C PD 보조배터리, 5 V 3 A 이상, 10 000–20 000 mAh | 1 | 주머니나 허리 가방에 넣음 | `USB-C PD power bank 20000mAh` | 20–45 |
| P2 | USB-C 케이블 1.5 m + 자석식 분리형(당기면 빠지는) USB-C 어댑터 (3 A) | 1세트 | 케이블이 목에 걸리는 사고 방지 | `magnetic USB-C breakaway adapter 3A` | 8–20 |
| W1 | 듀폰 점퍼선 F-F 20 cm (40개 묶음), M-F 20–30 cm 몇 개, TF-Luna용 **6핀** 1.25 mm 케이블 | 1세트 | I2C 모드에 5번 핀이 필요함 | `Dupont jumper wire female female 20cm` | 4–10 |
| W2 | 20 mm 벨크로(찍찍이) 스트랩 (200 mm) + 3M 듀얼락 / VHB 패드 | 1세트 | 스트랩 8–10개; 새들(받침 패드) 3개의 양면에 붙일 듀얼락 | `3M Dual Lock reclosable fastener` | 10–25 |
| W3 | SDA, SCL, 5 V, 3.3 V, GND 공유 선을 나누는 듀폰 1→N 암(F) 분배 케이블 | 1세트 | 또는 2 × 8 암 헤더 분배기. Qwiic/STEMMA 허브는 안 됨 (3.3 V 전용, JST-SH 커넥터) | `Dupont splitter 1 to 4 female` | 1–5 |
| W4 | USB-A 수 → 암 USB 연장 케이블, 10–15 cm | 1 | Pi 5 USB 2.0 포트 → 보조 포드의 오디오 어댑터 | `USB A male female extension 15cm` | 2–5 |
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

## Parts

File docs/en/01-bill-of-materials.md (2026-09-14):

# 01 · Bill of Materials

> Part of the Open Walking Safety Helmet · Licensed CC BY 4.0 · © 2026 CLSOFTLAB, Dr. Lee Il-guk

This page lists every part you need for the reference build, with approximate prices and where
to look for them. The authoritative part list is [§4.1 of the system design specification](00-system-design-spec.md#41-bill-of-materials-reference-build).
If this page and the spec ever disagree, the spec wins. Please open an issue so we can fix it.

> **Ready to order?** Use the [buying guide](10-buying-guide.md): verified purchase links, part numbers and the most common buying mistakes.

A machine-readable version is in [`../bom.csv`](../bom.csv) (now with official, global and Korean purchase-link columns). It includes columns for part, spec,
search keyword, price range and shop categories.

> **About prices.** All prices are **approximate ranges in US dollars, checked in September 2026**.
> They do not include shipping, import duty or VAT. Prices change often, especially for Raspberry Pi
> boards and memory. Compare at least two shops before you buy.

## Contents

- [Before you buy](#before-you-buy)
- [Reference build](#reference-build)
- [Optional parts](#optional-parts)
- [Printed parts and filament](#printed-parts-and-filament)
- [Total cost](#total-cost)
- [Budget variant](#budget-variant)
- [Where to buy](#where-to-buy)
- [Tools you need](#tools-you-need)

## Before you buy

- **The helmet must be new and certified.** Look for EN 1078 (Europe), CPSC 1203 (USA),
  AS/NZS 2063 (Australia/New Zealand), KC (Korea) or your country's equivalent. Choose a rounded
  shell with vents and no visor. Fit it to the person who will wear it. Never use a helmet that has
  already been in a crash.
- **Buy the TF-Luna with a 6-pin lead.** It uses a 6-pin 1.25 mm (GH) connector. Pin 5 selects I2C
  mode, so a 4-pin lead is not enough.
- **Buy coin motors with connectors or long leads.** The reference build uses no soldering.
- **Button modules must work at 3.3 V and be active-low.** Bare tactile switches are the simplest
  choice. See the [wiring guide](02-wiring-guide.md#step-6--buttons-b1b3).
- **Avoid unknown microSD cards.** A failing card is one of the most common causes of a helmet that
  stops working.

## Reference build

Refs match the spec, the wiring guide and the firmware.

| Ref | Part | Qty | Key spec | Search keyword | Unit price (USD, approx.) |
|---|---|---|---|---|---|
| H1 | Certified bicycle/multisport helmet with vents | 1 | EN 1078 / CPSC / AS/NZS / KC; vents ≥ 20 × 8 mm | `certified bicycle helmet EN 1078 vents` | 30–80 |
| U1 | Raspberry Pi 5, 4 GB (8 GB recommended) | 1 | 4 GB low end, 8 GB high end | `Raspberry Pi 5 8GB` | 60–120 |
| U2 | Raspberry Pi Active Cooler (official) | 1 | Required on Pi 5 | `Raspberry Pi 5 Active Cooler` | 5–8 |
| U3 | microSD 32 GB A2 | 1 | Known brand (or NVMe via M.2 HAT) | `microSD 32GB A2` | 8–15 |
| C1 | Raspberry Pi Camera Module 3 **Wide** | 1 | IMX708, 120° diagonal / 102° horizontal | `Raspberry Pi Camera Module 3 Wide` | 35–45 |
| C2 | Pi 5 camera cable 22-pin → 15-pin, 300 mm | 1 | FPC | `Raspberry Pi 5 camera cable 300mm` | 2–5 |
| S1 | Benewake **TF-Luna** LiDAR, forward | 1 | 0.2–8 m, 2° FOV, I2C mode | `Benewake TF-Luna LiDAR` | 18–35 |
| S2 | Benewake **TF-Luna** LiDAR, down-looking | 1 | Same, address changed to 0x11 | `Benewake TF-Luna LiDAR` | 18–35 |
| S3 | MPU-6050 (GY-521) IMU | 1 | I2C 0x68, fall detection | `GY-521 MPU-6050` | 2–5 |
| M1–M3 | Coin ERM vibration motor 1027, 3 V, with leads | 3 | 10 × 2.7 mm; left / centre / right | `1027 coin vibration motor 3V` | 0.5–2 each |
| D1 | ULN2003 driver board (from 28BYJ-48 kit) | 1 | Drives the 3 motors; sits in the aux pod | `ULN2003 driver board 28BYJ-48` | 1–3 |
| B1–B3 | 12 × 12 mm tactile switches (or 3-pin button modules, **3.3 V, active-low**) | 3 | Momentary | `12x12mm tactile switch` | 0.3–1.5 each |
| L1 | 3 mm LED + 330 Ω resistor (or LED module) | 1 | Status for sighted helpers | `3mm LED module` | 0.2–1 |
| A1 | USB audio adapter with a real mic input | 1 | Pi 5 has no 3.5 mm jack; sits in the aux pod. Must match the headset plug (4-pole TRRS combo jack, or split jacks + TRRS splitter) — see the [buying guide](10-buying-guide.md) | `USB audio adapter headphone mic` | 5–15 |
| A2 | Open-ear / bone-conduction wired headset with mic | 1 | Must not block the ears | `wired bone conduction headphones mic` | 15–60 |
| P1 | USB-C PD power bank, ≥ 5 V 3 A, 10 000–20 000 mAh | 1 | Pocket or waist bag | `USB-C PD power bank 20000mAh` | 20–45 |
| P2 | USB-C cable 1.5 m + magnetic breakaway USB-C adapter (3 A) | 1 set | Prevents neck snagging | `magnetic USB-C breakaway adapter 3A` | 8–20 |
| W1 | Dupont F-F 20 cm (40-pack), a few M-F 20–30 cm, **6-pin** 1.25 mm leads for TF-Luna | 1 set | Pin 5 is needed for I2C mode | `Dupont jumper wire female female 20cm` | 4–10 |
| W2 | 20 mm hook-and-loop straps (200 mm) + 3M Dual Lock / VHB pads | 1 set | 8–10 straps; Dual Lock for both faces of 3 saddles | `3M Dual Lock reclosable fastener` | 10–25 |
| W3 | Dupont 1-to-N female splitter cables for shared SDA, SCL, 5 V, 3.3 V and GND lines | 1 set | Or a 2 × 8 female header splitter. Not a Qwiic/STEMMA hub (3.3 V only, JST-SH plugs) | `Dupont splitter 1 to 4 female` | 1–5 |
| W4 | USB-A male → female extension cable, 10–15 cm | 1 | Pi 5 USB 2.0 port → audio adapter in the aux pod | `USB A male female extension 15cm` | 2–5 |
| F1 | M2.5 × 6 screws + 5 mm standoffs (Pi); M2 × 5 screws (camera, TF-Luna) | 1 set | The printed parts also use M2.5 × 8 pan head (lids) and M2 × 8 (pod cover), see [`hardware/README.md`](../../hardware/README.md) | `M2.5 standoff screw kit` | 5–10 |

## Optional parts

| Ref | Part | Qty | Why | Unit price (USD, approx.) |
|---|---|---|---|---|
| G1 | u-blox NEO-M8N GPS module (UART) | 0–1 | Location without a phone | 10–30 |
| R1 | TPU 95A filament for the rain gutter and rear nozzle | — | Passive rain management. About 95 g of TPU, more than the 60 g mass budget. | 2–4 (share) |

## Printed parts and filament

The printable parts (front pod, main case, aux pod, saddles, button housing, haptic pads, anchors,
clips, rain gutter) are listed in [03 · 3D printing guide](03-3d-printing-guide.md). Rigid parts are
PETG or ASA. Saddles, haptic pads and the rain gutter are TPU 95A. Strap anchors are PETG.
**Do not use PLA.** It softens in summer sun and in hot cars.

Filament is not a line in the spec BOM, so this guide adds an estimate (line PR1 in `bom.csv`):

- PETG or ASA: about **200 g** including supports (printed parts about 170 g, from the masses in
  [`hardware/README.md`](../../hardware/README.md)).
- TPU 95A: about **60 g** (three saddles about 41 g, three haptic pads about 9 g).
- Share of filament cost: about **USD 6–12**.

## Total cost

Totals are calculated from [`../bom.csv`](../bom.csv) (quantity × unit price).

- **Reference build (H1 to F1, plus the filament estimate): about USD 250–560.**
- Optional GPS and rain gutter filament: add about USD 12–34.
- Not included: shipping, tax, a 3D printer, tools, and a smartphone.

Where most of the money goes:

- Raspberry Pi 5 with cooler: USD 65–128
- Two TF-Luna LiDARs: USD 36–70
- Helmet: USD 30–80
- Headset: USD 15–60

If you do not own a printer, a local makerspace, library or online print service can print the
parts. Ask for PETG and TPU, not PLA.

## Budget variant

A cheaper build with a Raspberry Pi 4 and ST VL53L1X distance sensors would save about USD 40–100
(estimated total about USD 215–460).

> **The VL53L1X is NOT supported by firmware v1.0.** There is no VL53L1X driver yet; a future
> driver is on the [roadmap](08-patent-and-roadmap.md#610-vl53l1x-driver-for-a-budget-build).
> Until a driver exists and passes the [test plan](07-test-plan.md), a helmet with VL53L1X sensors
> has **no working head-height or drop-off warnings**. Do not use it as a walking aid.

### What changes

| Replaces | Budget part | Unit price (USD, approx.) |
|---|---|---|
| U1 Pi 5 | U1-B Raspberry Pi 4 Model B 4 GB | 55–75 |
| U2 Active Cooler | U2-B Pi 4 heatsink + 30 mm fan | 3–8 |
| C2 22→15-pin cable | C2-B 15→15-pin camera cable 300 mm | 1–4 |
| S1, S2 TF-Luna | S1-B, S2-B VL53L1X modules (**not supported yet**) | 5–15 each |
| A1 USB audio | A1-B use the Pi 4's 3.5 mm jack | 0 |

### Trade-offs

- **No firmware support.** See the warning above.
- **Much shorter outdoor range.** In the dark a VL53L1X reaches about 4 m. In bright sunlight
  its long-distance mode may reach well under 1 m. The down-looking sensor must see the ground about
  2.3 m away (spec §5.2). In daylight it would often get no return, which counts as a DROP. Expect many
  false drop alarms outdoors. The forward zones need 2.0 m and would also shrink.
- **Wider beam.** The VL53L1X field of view is about 27°, compared with 2° for the TF-Luna. It
  reacts to things beside the path, such as walls and poles.
- **Addresses are not stored.** Both VL53L1X sensors start at 0x29. Each needs its own XSHUT GPIO
  line so firmware can set a new address at every boot. The pin map in spec §4.2 has no lines for this.
- **Slower vision.** The Pi 4 runs the detector at a lower frame rate than the Pi 5. Test T3
  (≥ 8 FPS) is not expected to pass. Approach warnings come later.
- **Case fit.** The Pi 4 has the same mounting holes as the Pi 5, but its ports are in different
  places. Check the openings in `main_case_base` before printing, or adapt the model.
- **Sensor cradles.** VL53L1X modules do not fit the TF-Luna bays in the front pod.

**A supported cheaper option: keep both TF-Luna sensors and use a Raspberry Pi 4.** This keeps the
reflex path (spec P5) that firmware v1.0 supports, saves about USD 10–60, and only costs vision speed.

## Where to buy

Search keywords in the tables work on most shops. Shop names below are examples, not endorsements.

### Worldwide

- **Raspberry Pi boards, cooler, camera, cables:** Raspberry Pi Approved Resellers for your
  country (listed on raspberrypi.com), DigiKey, Mouser, Pimoroni.
- **TF-Luna, MPU-6050, ULN2003, motors, buttons, Dupont wires, splitters:** AliExpress (Benewake has an
  official store), DigiKey, Mouser, local electronics shops.
- **Helmet, power bank, headset, straps, USB extension:** local bike and sports shops, electronics stores,
  online retailers.

### Korea

- **Electronics:** 디바이스마트 (DeviceMart), 엘레파츠 (Eleparts), 아이씨뱅큐 (ICBanQ).
- **Helmet:** bicycle shops and sports stores. Check the KC mark.
- **Straps and fasteners:** large online malls, hardware stores.

## Tools you need

No soldering iron is needed.

- Small Phillips screwdrivers (PH0, PH1)
- Calipers, to check dimensions before printing (spec §4.4)
- A straight ruler, to measure the helmet shell radius ([03 · 3D printing guide](03-3d-printing-guide.md#2-measure-your-helmet-first))
- A phone inclinometer app, to measure the shell slope and sensor angles
- Flush cutters and a craft knife, for removing print supports
- A multimeter (recommended, for checking 5 V and continuity)
- A computer with a microSD card reader
- Labels or coloured tape for marking cables and the down-looking LiDAR

Next: [02 · Wiring guide](02-wiring-guide.md)

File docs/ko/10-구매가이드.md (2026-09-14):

> 오픈 보행 안전 헬멧의 일부 · CC BY 4.0 라이선스 · © 2026 씨엘소프트랩(CLSOFTLAB) 이일국 박사

# 10 · 구매 가이드 (실제 구매 링크)

이 문서는 **처음 만드는 분이 부품을 잘못 사지 않도록** 쇼핑몰별 장바구니 단위로 정리했습니다.
부품 사양은 [01 · 부품목록](01-부품목록.md), 전 세계 구매처는 [English buying guide](../en/10-buying-guide.md)를 보세요.

> [!IMPORTANT]
> - **가격과 재고는 2026년 9월 15일 기준**입니다. 부가세 포함이며 배송비는 따로입니다. 주문 전 다시 확인하세요.
> - **✅ 확인됨** = 상품 페이지를 직접 열어 상품명과 핵심 사양(모델명)을 확인한 링크입니다.
> - **🔍 검색** = 특정 상품을 보증할 수 없어 검색 결과로 연결됩니다. 표에 적힌 **고르는 조건**을 꼭 확인하세요.
> - 이 프로젝트는 쇼핑몰과 제휴하지 않았으며 링크로 수익을 얻지 않습니다.
> - 링크가 사라졌으면 **모델명**(SC1224, SC1129, SC1148, TF-Luna 등)으로 검색하면 같은 물건을 찾을 수 있습니다.

## 목차

- [주문 전에 꼭 알아야 할 7가지](#주문-전에-꼭-알아야-할-7가지)
- [장바구니 1 · 디바이스마트 (전자부품 대부분)](#장바구니-1--디바이스마트-전자부품-대부분)
- [장바구니 2 · 엘레파츠 (카메라)](#장바구니-2--엘레파츠-카메라)
- [장바구니 3 · 생활용품·소모품 (쿠팡·네이버 등)](#장바구니-3--생활용품소모품-쿠팡네이버-등)
- [대체 구매처](#대체-구매처)
- [예상 총비용](#예상-총비용)
- [선택 부품](#선택-부품)
- [라즈베리파이 한국 공식 리셀러](#라즈베리파이-한국-공식-리셀러)
- [택배를 받으면 바로 검수할 것](#택배를-받으면-바로-검수할-것)

---

## 주문 전에 꼭 알아야 할 7가지

1. **카메라는 반드시 "Camera Module 3 Wide"(모델명 SC1224)를 사세요.**
   일반형(75°), **NoIR**, **NoIR Wide**가 같은 목록에 나란히 있습니다.
   특히 디바이스마트는 2026-09-15 현재 Wide가 품절이고 바로 옆 **NoIR Wide만 구매 가능**합니다. NoIR은 적외선 필터가 없어 낮에 색이 틀어지니 사지 마세요.
2. **카메라 케이블은 따로 사야 합니다 (Pi 5용 22핀→15핀, 모델명 SC1129, 300mm).**
   Wide 카메라에 동봉된 케이블은 판매처마다 다르고, 15핀→15핀(Pi 4용)만 들어 있는 경우도 있습니다. 2~3천원이니 꼭 함께 주문하세요.
   엘레파츠는 이 케이블 이름이 "Camera Cable **Standard**"로 되어 있지만 실제로는 Pi 5용 SC1129입니다. "Display Cable"은 카메라에 쓸 수 없습니다.
3. **라이다는 "TF-Luna"여야 합니다.** 검색하면 TFmini Plus, TFmini-S, TF02 Pro가 섞여 나옵니다. 크기와 통신 방식이 달라 3D 부품에 맞지 않습니다.
   드론 카테고리의 CUAV "TF-Luna"는 약 3.5배 비싸니 피하세요.
4. **I2C 허브(Qwiic/STEMMA QT)는 사지 마세요.** 3.3V 전용이라 5V가 필요한 TF-Luna와 맞지 않습니다. **듀폰 분배 케이블**을 쓰세요.
5. **보조배터리는 출력 표에 "USB-C 5V⎓3A"가 적힌 제품만** 사세요. "PD 20W"라고만 적힌 제품은 5V에서 2A만 나오는 경우가 많고, 그러면 헬멧이 전원 부족 경고를 냅니다.
6. **골전도 헤드셋 플러그와 USB 오디오 어댑터 잭을 맞추세요.** 대부분의 헤드셋은 **4극 단일 플러그**(마이크 포함)입니다.
   아래 추천 어댑터는 헤드폰·마이크 **분리형 잭**이라 **4극→3극 2분배 젠더**가 함께 필요합니다.
7. **"ULN2003AP" / "ULN2003A(SMD)"는 칩 단품입니다.** 반드시 **드라이버 보드(모듈)**를 사세요.

---

## 장바구니 1 · 디바이스마트 (전자부품 대부분)

라즈베리파이 공식 리셀러(NTREX)의 판매처입니다. 한 번에 주문하면 배송비를 아낄 수 있습니다.

| 부품 | 상품 (링크) | 가격 | 수량 | 상태 | 주의 |
|---|---|---:|:---:|:---:|---|
| U1 라즈베리파이 5 8GB | [라즈베리파이5 (Raspberry Pi 5) 8GB + 가이드북](https://www.devicemart.co.kr/goods/view?no=15215449) | 322,300원 | 1 | ✅ | 가이드북 포함 상품. 케이스·어댑터 옵션은 **선택하지 마세요** (전용 케이스를 3D 출력함) |
| U2 액티브 쿨러 | [[정품] 라즈베리파이5 액티브 쿨러](https://www.devicemart.co.kr/goods/view?no=15276241) | 7,700원 | 1 | ✅ | 모델명 SC1148. Pi 5 필수 |
| C2 카메라 케이블 | [라즈베리파이5 FPC 카메라 케이블 300mm - 22P(0.5mm) to 15P(1mm)](https://www.devicemart.co.kr/goods/view?no=15285261) | 2,970원 | 1 | ✅ | 공식품 SC1129. 디스플레이용 아님 |
| S1·S2 TF-Luna 라이다 | [TF Luna LiDAR 거리 측정 센서 (0.2m~8m)](https://www.devicemart.co.kr/goods/view?no=12541520) | 39,600원 | **2** | ✅ | Benewake. 재고 소진 시 약 2주. 케이블 동봉 여부가 페이지에 없음 → 아래 W1-GH 참고 |
| S3 IMU | [MPU-6050 6축 자이로 가속도 센서 모듈 GY-521](https://www.devicemart.co.kr/goods/view?no=1247052) | 4,950원 | 1 | ✅ | 호환품 |
| M1–M3 진동모터 | [3V 코인형 DC 진동 모터 1027](https://www.devicemart.co.kr/goods/view?no=15959404) | 990원 | **3** (예비 포함 4) | ✅ | 리드선 길이는 사진으로 확인. 짧으면 듀폰 점퍼로 연장 |
| D1 모터 드라이버 | [ULN2003 아두이노 스텝모터 드라이버 모듈](https://www.devicemart.co.kr/goods/view?no=1287090) | 1,210원 | 1 | ✅ | 보드 단품. "ULN2003AP"(칩)와 헷갈리지 마세요 |
| B1–B3 버튼 | [택트스위치 DIP 12X12X7.3MM](https://www.devicemart.co.kr/goods/view?no=15959210) | 330원 | **3** (예비 포함 5) | ✅ | **높이 7.3mm DIP형**. 6mm·10mm·SMD형은 버튼 캡에 맞지 않음 |
| L1 LED | [3파이 고휘도 LED 반투명 (빨간색)](https://www.devicemart.co.kr/goods/view?no=2848) | 330원 (5개) | 최소 5 | ✅ | |
| L1 저항 330Ω | [1/4W 5% Axial Resistor 331J (330Ω)](https://www.devicemart.co.kr/goods/view?no=886) | 759원 (30개) | 최소 30 | ✅ | |
| A1 USB 오디오 | [유그린 U-30724 USB2.0 to Audio 컨버터](https://www.devicemart.co.kr/goods/view?no=14118701) | 14,960원 | 1 | ✅ | 헤드폰·마이크 **분리형 잭** → 장바구니 3의 4극→3극 젠더 필요 |
| P2 마그네틱 전원 케이블 | [C타입-C타입 100W 줄꼬임방지 마그네틱 케이블 **1.2M**](https://www.devicemart.co.kr/goods/view?no=15888761) | 12,760원 | 1 | ✅ | 목에 걸려도 떨어지는 안전장치. **1.2m 옵션**을 고르세요 (2m는 데이터 불가 표기) |
| W1 점퍼선 | [소켓 점퍼 케이블 40P (칼라) (F/F) 20cm](https://www.devicemart.co.kr/goods/view?no=1321192) | 935원 | **2** | ✅ | 암-암. 앞 센서까지 길이가 모자라면 서로 이어 씀 |
| W1-GH TF-Luna 케이블 | [Breadboard to JST-GHR-06V Cable - 6-Pin x 1.25mm](https://www.devicemart.co.kr/goods/view?no=14601284) | 4,290원 | 2 | ✅ | **TF-Luna에 케이블이 없을 때 대비.** 해외배송 1주, 반품 불가. 브레드보드 쪽이 수(male) 핀이면 위 F/F 점퍼로 이어서 Pi에 연결 |
| W3 분배 케이블 | [디바이스마트 검색: 점퍼 분배](https://www.devicemart.co.kr/goods/search?search_text=%EC%A0%90%ED%8D%BC%20%EB%B6%84%EB%B0%B0) | 약 2천~5천원 | 1세트 | 🔍 | **조건: 암(F) 1→2 또는 1→4 듀폰 분배.** Qwiic 허브 금지 |
| W4 USB 연장선 | [USB-A 2.0 M/F 연장케이블 NMC-UF203SB 0.3m](https://www.devicemart.co.kr/goods/view?no=12957574) | 2,090원 | 1 | ✅ | 15cm 제품이 없어 0.3m. 남는 길이는 케이블 클립으로 정리 |
| F1 M2.5 서포트 | [M2.5 황동 서포트 키트 (15종)](https://www.devicemart.co.kr/goods/view?no=1360152) | 15,400원 | 1 | ✅ | M2.5만 있음 |
| F1 M2 볼트 | [디바이스마트 검색: M2 볼트](https://www.devicemart.co.kr/goods/search?search_text=M2%20%EB%B3%BC%ED%8A%B8) | 약 2천원 | 5mm·8mm 각 10개 | 🔍 | 카메라·TF-Luna·센서 커버 고정용 |

## 장바구니 2 · 엘레파츠 (카메라)

| 부품 | 상품 (링크) | 가격 | 수량 | 상태 | 주의 |
|---|---|---:|:---:|:---:|---|
| C1 카메라 | [Camera Module 3 Wide (라즈베리파이 카메라모듈 3 Wide)](https://www.eleparts.co.kr/goods/view?no=12391455) | 56,100원 | 1 | ✅ | 모델명 **SC1224**, 재고 있음(24시간 내 발송). 페이지에 Pi 5용 200mm 케이블 포함으로 되어 있지만, 헬멧에는 길이가 짧아 **300mm(C2)를 따로 사세요** |

> 엘레파츠에서 라즈베리파이·쿨러·케이블까지 한 번에 사도 됩니다: [Pi 5 8GB](https://www.eleparts.co.kr/goods/view?no=13323153) 320,100원 ✅ ·
> [액티브 쿨러](https://www.eleparts.co.kr/goods/view?no=13535082) 7,700원 ✅ ·
> [카메라 케이블 300mm (이름은 Standard, 실제 SC1129)](https://www.eleparts.co.kr/goods/view?no=13535083) 3,080원 ✅ ·
> [TF Luna **I2C**](https://www.eleparts.co.kr/goods/view?no=10033857) 39,400원 ✅ (해외, 약 6.5일. 같은 곳의 "TF Luna Uart" 말고 **I2C** 상품을 고르세요)

## 장바구니 3 · 생활용품·소모품 (쿠팡·네이버 등)

전자부품몰에 없거나 상품이 자주 바뀌는 품목입니다. **고르는 조건을 모두 만족하는 제품**을 고르세요.

> 쿠팡 검색 링크는 자동 점검 도구의 접속이 차단되어 이 문서 작성 시 열어 보지 못했습니다. 일반 브라우저에서 열리지 않으면
> 같은 검색어로 [11번가](https://search.11st.co.kr/Search.tmall?kwd=%EB%B3%B4%EC%A1%B0%EB%B0%B0%ED%84%B0%EB%A6%AC+5V3A)나 네이버쇼핑에서 찾으세요.

| 부품 | 검색 링크 | 예상 가격 | 고르는 조건 (모두 확인) |
|---|---|---:|---|
| H1 헬멧 | [쿠팡: KC인증 자전거 헬멧](https://www.coupang.com/np/search?q=KC%EC%9D%B8%EC%A6%9D+%EC%9E%90%EC%A0%84%EA%B1%B0+%ED%97%AC%EB%A9%A7) | 3만~8만원 | **KC 인증 표시**, 새 제품, 통풍구 폭 20mm 이상, 둥근 셸, 챙 없는 형태, 사용자 머리 둘레에 맞는 사이즈 |
| U3 microSD | [쿠팡: microSD 32GB A2](https://www.coupang.com/np/search?q=microSD+32GB+A2) | 8천~1만5천원 | 카드나 설명에 **A2** 표기 (Class10만 적힌 것은 A2 아님), 유명 브랜드 공식 판매 |
| A2 골전도 헤드셋 | [쿠팡: 골전도 이어폰 유선 마이크 3.5mm](https://www.coupang.com/np/search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) | 3만~7만원 | **유선 3.5mm**, 마이크 포함, 귀를 막지 않는 골전도/오픈형. 블루투스 전용 제품은 안 됨 |
| A2 젠더 | [쿠팡: 4극 3극 분배 젠더 마이크 헤드폰](https://www.coupang.com/np/search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) | 2천~5천원 | **4극 암(헤드셋 쪽) → 3극 수 2개(헤드폰 + 마이크)** 방향. 반대 방향(3극 2개 → 4극) 젠더는 안 맞음 |
| P1 보조배터리 | [쿠팡: 보조배터리 PD 5V3A 20000mAh](https://www.coupang.com/np/search?q=%EB%B3%B4%EC%A1%B0%EB%B0%B0%ED%84%B0%EB%A6%AC+PD+5V3A+20000mAh) | 2만5천~4만5천원 | 출력 표에 **USB-C 5V⎓3A** 명시, 10,000~20,000mAh, KC 인증. "PD 20W"만 적힌 제품은 5V3A 확인 전에는 사지 마세요 |
| W2 3M 듀얼락 | [쿠팡: 3M 듀얼락](https://www.coupang.com/np/search?q=3M+%EB%93%80%EC%96%BC%EB%9D%BD) | 1만~2만원 | **3M Dual Lock 정품** 소포장 (산업용 대형 롤은 불필요) |
| W2 벨크로 스트랩 | [쿠팡: 벨크로 케이블타이 20mm](https://www.coupang.com/np/search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) | 5천~1만원 | 폭 **20mm**, 길이 200mm 이상, 6~8개 (스트랩 구멍 21×3.2mm에 통과) |
| PR1 PETG 필라멘트 | [쿠팡: PETG 필라멘트 1.75](https://www.coupang.com/np/search?q=PETG+%ED%95%84%EB%9D%BC%EB%A9%98%ED%8A%B8+1.75) | 2만~3만원 (1kg) | **PETG 또는 ASA**, 1.75mm. PLA는 여름 햇볕에 휘어서 안 됨 |
| PR1 TPU 필라멘트 | [쿠팡: TPU 95A 필라멘트 1.75](https://www.coupang.com/np/search?q=TPU+95A+%ED%95%84%EB%9D%BC%EB%A9%98%ED%8A%B8+1.75) | 2만~3만5천원 | **95A** 경도, 1.75mm (받침·진동 패드·빗물 유로용) |

3D 프린터가 없으면 지역 메이커스페이스나 3D 출력 대행 서비스에 [`hardware/stl/`](../../hardware/stl/) 파일을 맡기세요.

---

## 대체 구매처

품절일 때 쓰세요. 모두 ✅ 확인한 링크입니다.

| 부품 | 대체 상품 | 가격 | 비고 |
|---|---|---:|---|
| U1 Pi 5 8GB | [아이씨뱅큐 라즈베리파이 5 8GB](https://www.icbanq.com/P015956550) | 322,300원 | 배송 1~2일 |
| U1 Pi 5 **4GB** | [아이씨뱅큐 라즈베리파이 5 4GB](https://www.icbanq.com/P015956549) | 217,800원 | 당일출고. 디바이스마트·엘레파츠 4GB는 품절 |
| C1 카메라 Wide | [아이씨뱅큐 Camera Module 3 Wide (IR cut filter)](https://www.icbanq.com/P015430879) | 53,460원 | 해외, 2주 이내. **같은 이름의 P015987269(234,971원, 최소 2개)는 중개 상품이니 피하세요** |
| S1·S2 TF-Luna | [아이씨뱅큐 TF-Luna (DFRobot SEN0340)](https://www.icbanq.com/P011442809) | 38,940원 | 해외, 1주 이내. DFRobot 판매분은 케이블(Wiring) 동봉으로 알려짐 |
| A1 USB 오디오 | [엘레파츠 벤션 USB 외장형 사운드카드 3극 마이크 오디오 분리형 CVHHC](https://www.eleparts.co.kr/goods/view?no=18708902) | 16,600원 | 분리형 잭 (젠더 필요) |

**4GB로 충분한가요?** 네. 펌웨어는 4GB로 동작합니다. 8GB는 여유 메모리 때문에 권장할 뿐입니다.

## 예상 총비용

| 구성 | 확인된 부품 합계 | 조건 보고 고르는 품목 포함 총액 |
|---|---:|---:|
| 기본 (Pi 5 **8GB**) | 약 53만5천원 | **약 69만~85만원** |
| 절약 (Pi 5 **4GB**, 아이씨뱅큐) | 약 43만원 | **약 58만~75만원** |

- 배송비와 3D 프린터 값은 빠진 금액입니다.
- 가장 비싼 품목은 라즈베리파이(4GB 22만원, 8GB 32만원), TF-Luna 2개(약 8만원), 헤드셋, 헬멧 순입니다.
- 2026년 현재 메모리 가격 상승으로 라즈베리파이 값이 예전보다 높습니다.

## 선택 부품

| 부품 | 상품 | 가격 | 상태 | 비고 |
|---|---|---:|:---:|---|
| G1 GPS (휴대폰 없이 위치) | [NEO-M8N GPS 모듈](https://www.devicemart.co.kr/goods/view?no=15106909) | 39,600원 | ✅ | 호환 모델이라 u-blox 정품 칩 보장 없음. "ATGM336H GPS 모듈 NEO-M8N"은 **다른 칩**이니 주의 |

## 라즈베리파이 한국 공식 리셀러

[raspberrypi.com/resellers](https://www.raspberrypi.com/resellers/)의 대한민국 목록(2026-09-15 확인):
[NTREX(디바이스마트)](https://www.devicemart.co.kr/) · [엘레파츠](https://www.eleparts.co.kr/) · [Leocom](https://www.leocom.kr/RaspberryPi/) · [Insem](http://www.insem.co.kr/) · 해외 업체 Digi-Key, element14, Mouser.
아이씨뱅큐는 공식 목록에 없지만 KC 인증(R-R-P2R-RP5) 정품을 판매합니다.

---

## 택배를 받으면 바로 검수할 것

반품 기간 안에 확인해야 합니다. 특히 해외배송 상품은 반품이 안 됩니다.

- [ ] 라즈베리파이 박스에 **Raspberry Pi 5**와 RAM 용량(4GB/8GB)이 적혀 있다
- [ ] 쿨러 모델명 **SC1148**, 파이 5 전용
- [ ] 카메라 박스에 **Camera Module 3 Wide** 표기 (NoIR 아님). 렌즈가 일반형보다 넓고 볼록함
- [ ] 카메라 케이블 한쪽이 **좁은 22핀(0.5mm)**, 다른 쪽이 **넓은 15핀(1mm)**, 케이블에 "CAMERA" 인쇄, 길이 약 300mm
- [ ] 라이다 라벨에 **TF-Luna** (TFmini 아님), 6핀 커넥터, 케이블 동봉 여부 확인
- [ ] ULN2003은 칩이 아니라 **보드**(빨간 LED 4개와 핀 헤더가 있는 초록 기판)
- [ ] 택트스위치 높이 **7.3mm**
- [ ] 보조배터리 뒷면 출력 표에 **5V⎓3A**
- [ ] 마그네틱 케이블 **1.2m**, 데이터 전송 가능 표기
- [ ] 헤드셋 플러그와 오디오 어댑터(+젠더)가 실제로 맞물림
- [ ] 필라멘트가 **PETG(또는 ASA)**와 **TPU 95A**

모두 확인했으면 [02 · 배선 가이드](02-배선가이드.md)와 [03 · 3D 프린팅 가이드](03-3D프린팅가이드.md)로 넘어가세요.

## 링크가 틀렸거나 품절이면

[GitHub 이슈](https://github.com/clsoftlab-lang/open-walking-safety-helmet/issues)로 알려주세요. 다른 제작자들이 같은 실수를 하지 않게 됩니다.

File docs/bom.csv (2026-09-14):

ref | build | part | qty | unit | spec | search_keyword | unit_price_usd_low | unit_price_usd_high | where_to_buy_global | where_to_buy_korea | notes | url_official | url_global | url_korea | links_checked
H1 | reference | Certified bicycle/multisport helmet with vents | 1 | pc | EN 1078 / CPSC 1203 / AS/NZS 2063 / KC mark; rounded shell, no visor; vents >= 20 x 8 mm | certified bicycle helmet EN 1078 vents | 30 | 80 | Local bike shops, sporting goods stores, online retailers | 자전거 매장, 스포츠용품점, 온라인 쇼핑몰 (KC 인증 표시 확인) | Buy new. Size to the user. Never a used or crashed helmet. |  |  | https://www.coupang.com/np/search | 2026-09-15 (see docs/en/10-buying-guide.md for verified vs search links)
U1 | reference | Raspberry Pi 5 (4 GB; 8 GB recommended) | 1 | pc | BCM2712 quad-core; 4 GB or 8 GB RAM | Raspberry Pi 5 8GB | 60 | 120 | Raspberry Pi Approved Resellers (see raspberrypi.com/resellers); DigiKey; Mouser | 디바이스마트, 엘레파츠, 아이씨뱅큐 (Raspberry Pi 공식 리셀러 여부 확인) | Low end = 4 GB; high end = 8 GB. | https://www.raspberrypi.com/products/raspberry-pi-5/ | https://www.digikey.com/en/products/detail/raspberry-pi/SC1112/21658257 | https://www.devicemart.co.kr/goods/view?no=15215449 | 2026-09-15 (see docs/en/10-buying-guide.md for verified vs search links)
U2 | reference | Raspberry Pi Active Cooler (official) | 1 | pc | Official heatsink + fan for Pi 5 | Raspberry Pi 5 Active Cooler | 5 | 8 | Raspberry Pi Approved Resellers; DigiKey; Mouser | 디바이스마트, 엘레파츠, 아이씨뱅큐 | Required on Pi 5. | https://www.raspberrypi.com/products/active-cooler/ | https://www.digikey.com/en/products/detail/raspberry-pi/SC1148/21658255 | https://www.devicemart.co.kr/goods/view?no=15276241 | 2026-09-15 (see docs/en/10-buying-guide.md for verified vs search links)
U3 | reference | microSD card 32 GB A2 | 1 | pc | 32 GB, A2 / U3 rated, reputable brand | microSD 32GB A2 | 8 | 15 | Electronics retailers, AliExpress (buy a known brand from an official store) | 디바이스마트, 엘레파츠, 아이씨뱅큐, 대형 온라인몰 | Or NVMe via M.2 HAT (not priced here). | https://www.raspberrypi.com/products/sd-cards/ | https://www.aliexpress.com/w/wholesale-microsd-32gb-a2.html | https://www.coupang.com/np/search?q=microSD+32GB+A2 | 2026-09-15 (see docs/en/10-buying-guide.md for verified vs search links)
C1 | reference | Raspberry Pi Camera Module 3 Wide | 1 | pc | IMX708, 120 deg diagonal / 102 deg horizontal, autofocus | Raspberry Pi Camera Module 3 Wide | 35 | 45 | Raspberry Pi Approved Resellers; DigiKey; Mouser | 디바이스마트, 엘레파츠, 아이씨뱅큐 | Standard (non-NoIR) version. | https://www.raspberrypi.com/products/camera-module-3/ | https://www.digikey.com/en/products/detail/raspberry-pi/SC0874/17278644 | https://www.eleparts.co.kr/goods/view?no=12391455 | 2026-09-15 (see docs/en/10-buying-guide.md for verified vs search links)
C2 | reference | Pi 5 camera cable 22-pin to 15-pin 300 mm | 1 | pc | FPC, 22-pin (Pi 5 side) to 15-pin (camera side), 300 mm | Raspberry Pi 5 camera cable 300mm | 2 | 5 | Raspberry Pi Approved Resellers; AliExpress; DigiKey | 디바이스마트, 엘레파츠, 아이씨뱅큐 | Check helmet front-to-rear routing length before ordering; 500 mm exists if needed. | https://www.raspberrypi.com/products/camera-cable/ | https://www.digikey.com/en/products/detail/raspberry-pi/SC1129/21658260 | https://www.devicemart.co.kr/goods/view?no=15285261 | 2026-09-15 (see docs/en/10-buying-guide.md for verified vs search links)
S1 | reference | Benewake TF-Luna LiDAR (forward) | 1 | pc | 0.2-8 m, 2 deg FOV, I2C/UART, 5 V | Benewake TF-Luna LiDAR | 18 | 35 | AliExpress (Benewake official store); DigiKey; Mouser; SparkFun/Pimoroni distributors | 디바이스마트, 엘레파츠, 아이씨뱅큐 | Make sure the 6-pin GH1.25 cable is included. | https://en.benewake.com/TFLuna/index.html | https://www.dfrobot.com/product-1995.html | https://www.devicemart.co.kr/goods/view?no=12541520 | 2026-09-15 (see docs/en/10-buying-guide.md for verified vs search links)
S2 | reference | Benewake TF-Luna LiDAR (down-looking) | 1 | pc | Same as S1; I2C address changed to 0x11 | Benewake TF-Luna LiDAR | 18 | 35 | AliExpress (Benewake official store); DigiKey; Mouser | 디바이스마트, 엘레파츠, 아이씨뱅큐 |  | https://en.benewake.com/TFLuna/index.html | https://www.dfrobot.com/product-1995.html | https://www.devicemart.co.kr/goods/view?no=12541520 | 2026-09-15 (see docs/en/10-buying-guide.md for verified vs search links)
S3 | reference | MPU-6050 IMU module (GY-521) | 1 | pc | 3-axis accel + gyro, I2C 0x68, 3.3-5 V | GY-521 MPU-6050 | 2 | 5 | AliExpress; DigiKey (breakout boards); local electronics shops | 디바이스마트, 엘레파츠, 아이씨뱅큐 | Leave AD0 unconnected (address 0x68). |  | https://www.aliexpress.com/w/wholesale-gy-521-mpu6050.html | https://www.devicemart.co.kr/goods/view?no=1247052 | 2026-09-15 (see docs/en/10-buying-guide.md for verified vs search links)
M1-M3 | reference | Coin ERM vibration motor 1027 with leads | 3 | pc | 10 x 2.7 mm, 3 V | 1027 coin vibration motor 3V | 0.5 | 2 | AliExpress; DigiKey; Mouser | 디바이스마트, 엘레파츠, 아이씨뱅큐 | Prefer versions with a 2-pin connector or longer leads (no soldering). |  | https://www.adafruit.com/product/1201 | https://www.devicemart.co.kr/goods/view?no=15959404 | 2026-09-15 (see docs/en/10-buying-guide.md for verified vs search links)
D1 | reference | ULN2003 driver board | 1 | pc | From 28BYJ-48 stepper kit; IN1-IN4, OUT1-OUT4, +/- power pins | ULN2003 driver board 28BYJ-48 | 1 | 3 | AliExpress; local electronics shops | 디바이스마트, 엘레파츠, 아이씨뱅큐 | Sits in the aux pod. Price for board alone; kit with stepper costs a little more. |  | https://www.aliexpress.com/w/wholesale-uln2003-driver-board-28byj-48.html | https://www.devicemart.co.kr/goods/view?no=1287090 | 2026-09-15 (see docs/en/10-buying-guide.md for verified vs search links)
B1-B3 | reference | 12 x 12 mm tactile switch (bare) or 3-pin button module | 3 | pc | 12 x 12 x 7.3 mm tactile switch, momentary | 12x12mm tactile switch | 0.3 | 1.5 | AliExpress; DigiKey; Mouser | 디바이스마트, 엘레파츠, 아이씨뱅큐 | Bare switch + 2 Dupont wires matches active-low wiring directly. |  | https://www.sparkfun.com/momentary-pushbutton-switch-12mm-square.html | https://www.devicemart.co.kr/goods/view?no=15959210 | 2026-09-15 (see docs/en/10-buying-guide.md for verified vs search links)
L1 | reference | 3 mm LED + 330 ohm resistor (or LED module) | 1 | pc | 3 mm LED, 330 ohm series resistor | 3mm LED module | 0.2 | 1 | AliExpress; DigiKey; local electronics shops | 디바이스마트, 엘레파츠, 아이씨뱅큐 | Status light for sighted helpers. |  |  | https://www.devicemart.co.kr/goods/view?no=2848 ; https://www.devicemart.co.kr/goods/view?no=886 | 2026-09-15 (see docs/en/10-buying-guide.md for verified vs search links)
A1 | reference | USB audio adapter with headphone + mic jacks | 1 | pc | USB 2.0, class-compliant, real microphone input (not line-in); 4-pole TRRS combo jack or separate jacks + TRRS splitter to match the headset | USB audio adapter headphone mic | 5 | 15 | AliExpress; electronics retailers | 디바이스마트, 엘레파츠, 대형 온라인몰 | Pi 5 has no 3.5 mm jack. Sits in the aux pod on the W4 extension. |  | https://www.adafruit.com/product/1475 | https://www.devicemart.co.kr/goods/view?no=14118701 | 2026-09-15 (see docs/en/10-buying-guide.md for verified vs search links)
A2 | reference | Open-ear / bone-conduction wired headset with mic | 1 | pc | Wired 3.5 mm, does not block the ear canal | wired bone conduction headphones mic | 15 | 60 | Online retailers; electronics stores | 대형 온라인몰, 전자제품 매장 | Must leave ears open to traffic sounds. |  | https://www.aliexpress.com/w/wholesale-wired-bone-conduction-headphones-microphone.html | https://www.coupang.com/np/search | 2026-09-15 (see docs/en/10-buying-guide.md for verified vs search links)
P1 | reference | USB-C PD power bank 10 000-20 000 mAh | 1 | pc | >= 5 V 3 A output, USB-C PD | USB-C PD power bank 20000mAh | 20 | 45 | Electronics retailers; online retailers | 대형 온라인몰, 전자제품 매장 | Carried in pocket or waist bag. Airline rules apply to large batteries. |  | https://www.aliexpress.com/w/wholesale-usb-c-pd-power-bank-20000mah.html | https://www.coupang.com/np/search?q=%EB%B3%B4%EC%A1%B0%EB%B0%B0%ED%84%B0%EB%A6%AC+PD+5V3A+20000mAh | 2026-09-15 (see docs/en/10-buying-guide.md for verified vs search links)
P2 | reference | USB-C cable 1.5 m + magnetic breakaway USB-C adapter (3 A) | 1 | set | 1.5 m USB-C cable; magnetic breakaway adapter rated >= 3 A | magnetic USB-C breakaway adapter 3A | 8 | 20 | AliExpress; online retailers | 대형 온라인몰, 알리익스프레스 | Breakaway prevents neck snagging. |  | https://www.adafruit.com/product/5521 | https://www.devicemart.co.kr/goods/view?no=15888761 | 2026-09-15 (see docs/en/10-buying-guide.md for verified vs search links)
W1 | reference | Dupont jumper wires F-F 20 cm (40-pack) + 6-pin 1.25 mm leads for TF-Luna | 1 | set | Dupont F-F 20 cm (40); a few M-F 20-30 cm; 6-pin 1.25 mm (GH) to Dupont female leads x2 (pin 5 is needed for I2C mode) | Dupont jumper wire female female 20cm | 4 | 10 | AliExpress; DigiKey; local electronics shops | 디바이스마트, 엘레파츠, 아이씨뱅큐 | Longer leads (30-40 cm) help reach the front pod and aux pod from the main case. |  | https://www.adafruit.com/product/266 | https://www.devicemart.co.kr/goods/view?no=1321192 ; https://www.devicemart.co.kr/goods/view?no=14601284 | 2026-09-15 (see docs/en/10-buying-guide.md for verified vs search links)
W2 | reference | 20 mm hook-and-loop straps (200 mm) + 3M Dual Lock / VHB pads | 1 | set | 20 mm x 200 mm straps (x6-8); 3M Dual Lock reclosable fastener; VHB pads | 3M Dual Lock reclosable fastener 25mm | 10 | 25 | AliExpress; hardware stores; online retailers | 대형 온라인몰, 철물점, 다이소(벨크로 끈) | Buy genuine 3M Dual Lock where possible. | https://www.3m.com/3M/en_US/p/d/b40072057/ |  | https://www.coupang.com/np/search?q=3M+%EB%93%80%EC%96%BC%EB%9D%BD | 2026-09-15 (see docs/en/10-buying-guide.md for verified vs search links)
W3 | reference | Dupont female 1-to-N splitter cables for shared SDA, SCL, 5 V, 3.3 V and GND lines | 1 | pc | Dupont female 1-to-2 / 1-to-4 splitters or 2x8 female header splitter. NOT a Qwiic/STEMMA QT hub (3.3 V only, JST-SH plugs) | Dupont splitter 1 to 4 female | 1 | 5 | AliExpress; local electronics shops | 디바이스마트, 엘레파츠, 아이씨뱅큐 | 3 I2C devices and several 5 V loads share header pins. |  | https://www.aliexpress.com/w/wholesale-dupont-splitter-female.html | https://www.devicemart.co.kr/goods/search?search_text=%EC%A0%90%ED%8D%BC%20%EB%B6%84%EB%B0%B0 | 2026-09-15 (see docs/en/10-buying-guide.md for verified vs search links)
W4 | reference | USB-A male to female extension cable 10-15 cm | 1 | pc | USB 2.0, 10-15 cm, slim plugs | USB A male female extension 15cm | 2 | 5 | AliExpress; electronics retailers | 디바이스마트, 엘레파츠, 대형 온라인몰 | Pi 5 USB 2.0 port -> USB audio adapter in the aux pod. |  | https://www.aliexpress.com/w/wholesale-usb-a-male-female-extension-15cm.html | https://www.devicemart.co.kr/goods/view?no=12957574 | 2026-09-15 (see docs/en/10-buying-guide.md for verified vs search links)
F1 | reference | M2.5 x 6 screws + 5 mm standoffs; M2 x 5 screws | 1 | set | M2.5 x 6 (x4) + 5 mm standoffs (x4) for the Pi; M2 x 5 (x8) camera and TF-Luna; hardware/README.md also uses M2.5 x 8 pan head (x8, lids) and M2 x 8 (x4, pod cover) | M2.5 standoff screw kit | 5 | 10 | AliExpress; hardware suppliers | 디바이스마트, 엘레파츠, 철물점 | A kit with assorted lengths is useful. |  | https://www.adafruit.com/product/3299 | https://www.devicemart.co.kr/goods/view?no=1360152 | 2026-09-15 (see docs/en/10-buying-guide.md for verified vs search links)
PR1 | reference-added | Filament for printed parts (PETG/ASA ~200 g incl. supports + TPU 95A ~60 g) | 1 | set | PETG or ASA 1.75 mm; TPU 95A 1.75 mm | PETG filament 1.75mm | 6 | 12 | Filament brands' stores; AliExpress; local 3D printing shops | 3D프린팅 소재 쇼핑몰, 대형 온라인몰 | Not a spec BOM line (cost estimate). Based on masses in hardware/README.md. A full 1 kg spool is about USD 15-30. |  |  | https://www.coupang.com/np/search?q=PETG+%ED%95%84%EB%9D%BC%EB%A9%98%ED%8A%B8+1.75 | 2026-09-15 (see docs/en/10-buying-guide.md for verified vs search links)
G1 | optional | u-blox NEO-M8N GPS module (UART) | 1 | pc | UART 9600 baud, with antenna | NEO-M8N GPS module | 10 | 30 | AliExpress; DigiKey; Mouser | 디바이스마트, 엘레파츠, 아이씨뱅큐 | Phone-free location. Not included in total. | https://www.u-blox.com/en/product/neo-m8-series | https://www.aliexpress.com/w/wholesale-neo-m8n-gps-module.html | https://www.devicemart.co.kr/goods/view?no=15106909 | 2026-09-15 (see docs/en/10-buying-guide.md for verified vs search links)
R1 | optional | TPU 95A filament for rain gutter | 1 | set | TPU 95A 1.75 mm, ~95 g for 4 gutter segments + nozzle | TPU 95A filament | 2 | 4 | Filament brands' stores; AliExpress | 3D프린팅 소재 쇼핑몰, 대형 온라인몰 | Not included in total. Gutter is heavier than its 60 g budget (see hardware/README.md). |  |  | https://www.coupang.com/np/search?q=TPU+95A+%ED%95%84%EB%9D%BC%EB%A9%98%ED%8A%B8+1.75 | 2026-09-15 (see docs/en/10-buying-guide.md for verified vs search links)
U1-B | budget-substitute | Raspberry Pi 4 Model B 4 GB (replaces U1) | 1 | pc | BCM2711, 4 GB | Raspberry Pi 4 Model B 4GB | 55 | 75 | Raspberry Pi Approved Resellers; DigiKey; Mouser | 디바이스마트, 엘레파츠, 아이씨뱅큐 | Lower vision frame rate; T3 (>= 8 FPS) is not expected to pass. | https://www.raspberrypi.com/products/raspberry-pi-4-model-b/ |  |  | 2026-09-15 (see docs/en/10-buying-guide.md for verified vs search links)
U2-B | budget-substitute | Pi 4 heatsink + small fan (replaces U2) | 1 | set | Aluminium heatsink set + 30 mm 5 V fan | Raspberry Pi 4 heatsink fan | 3 | 8 | AliExpress; Raspberry Pi resellers | 디바이스마트, 엘레파츠, 아이씨뱅큐 | Pi 4 throttles in a closed case without cooling.
C2-B | budget-substitute | Camera cable 15-pin to 15-pin 300 mm (replaces C2) | 1 | pc | FPC 15-pin both ends, 300 mm | Raspberry Pi camera cable 15 pin 300mm | 1 | 4 | AliExpress; Raspberry Pi resellers | 디바이스마트, 엘레파츠, 아이씨뱅큐 | Pi 4 uses the 15-pin connector.
S1-B | budget-substitute | VL53L1X ToF distance sensor module (replaces S1) | 1 | pc | ST VL53L1X, I2C 0x29 default, up to ~4 m in the dark, much less in sunlight | VL53L1X module | 5 | 15 | AliExpress; Pololu/SparkFun/Adafruit distributors; DigiKey | 디바이스마트, 엘레파츠, 아이씨뱅큐 | NOT supported by firmware v1.0 (no driver yet; a future driver is on the roadmap). Needs an XSHUT GPIO per sensor. Short outdoor range.
S2-B | budget-substitute | VL53L1X ToF distance sensor module (replaces S2) | 1 | pc | Same as S1-B | VL53L1X module | 5 | 15 | AliExpress; Pololu/SparkFun/Adafruit distributors; DigiKey | 디바이스마트, 엘레파츠, 아이씨뱅큐 | NOT supported by firmware v1.0 (no driver yet; a future driver is on the roadmap). Needs an XSHUT GPIO per sensor. Short outdoor range.
A1-B | budget-substitute | No USB audio adapter (use Pi 4 3.5 mm jack) (replaces A1) | 1 | pc | Pi 4 on-board 3.5 mm audio | — | 0 | 0 | — | — | Pi 4 on-board jack; the headset cable then runs to the main case instead of the aux pod.

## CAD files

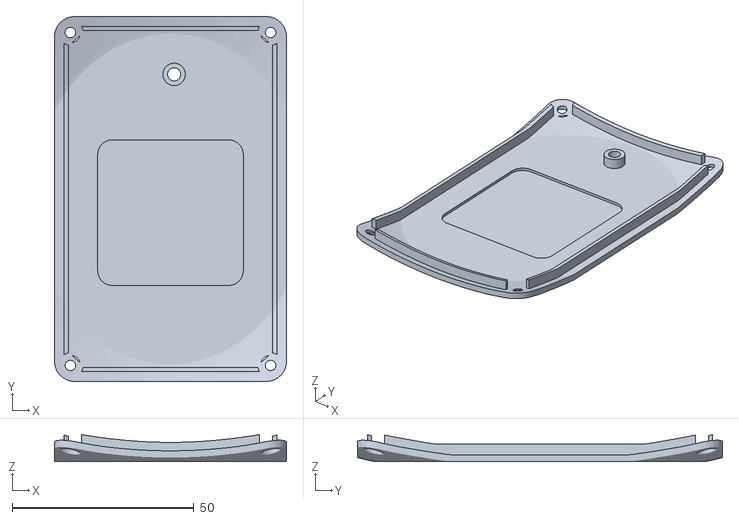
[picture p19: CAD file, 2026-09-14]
hardware/stl/main_case_lid.stl
63.8 x 100.3 x 7.42

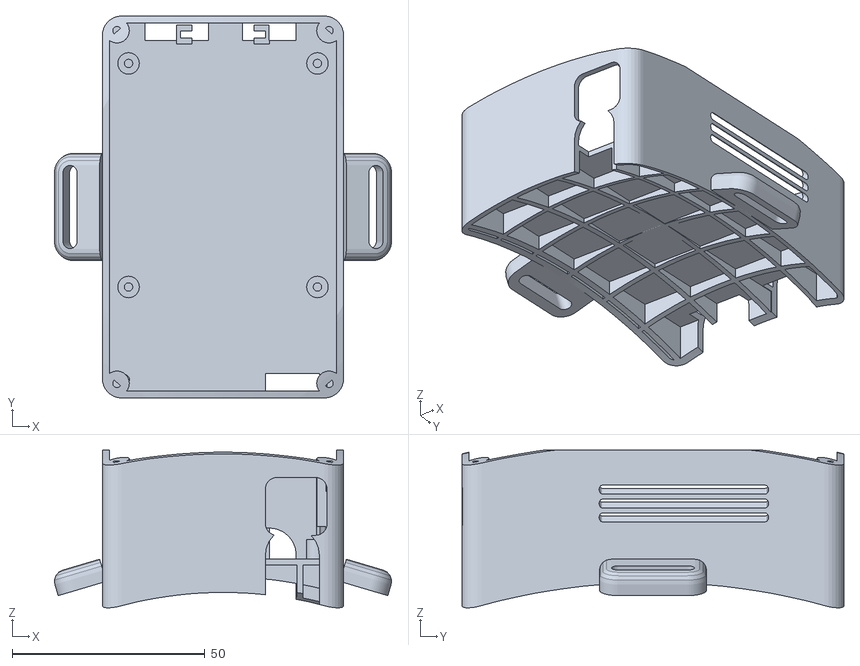
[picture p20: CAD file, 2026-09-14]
hardware/stl/worn/main_case_base.stl
87.5 x 99.1 x 40.9

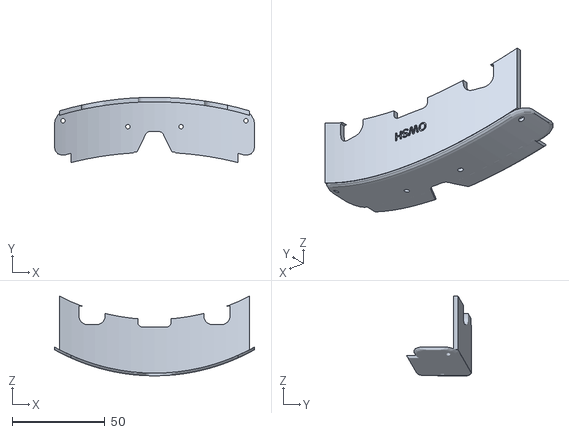
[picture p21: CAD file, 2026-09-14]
hardware/stl/front_pod_cover.stl
107.6 x 35.1 x 42.9

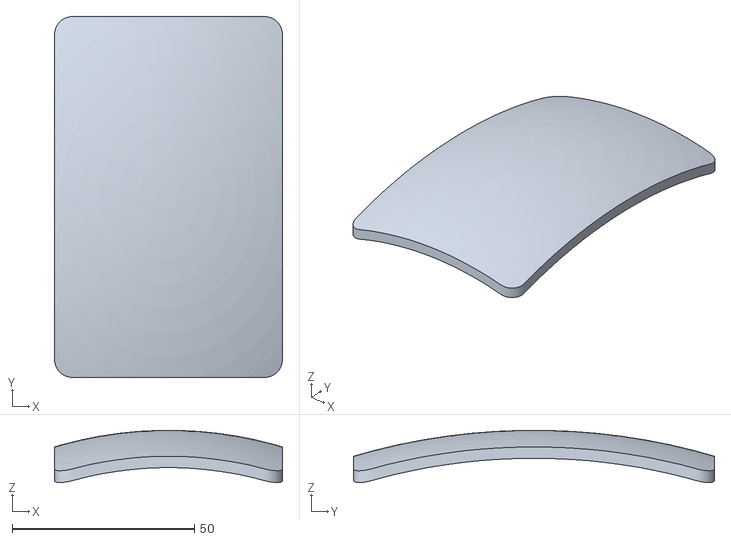
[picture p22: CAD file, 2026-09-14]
hardware/stl/worn/saddle_case.stl
62.6 x 99.1 x 14.3

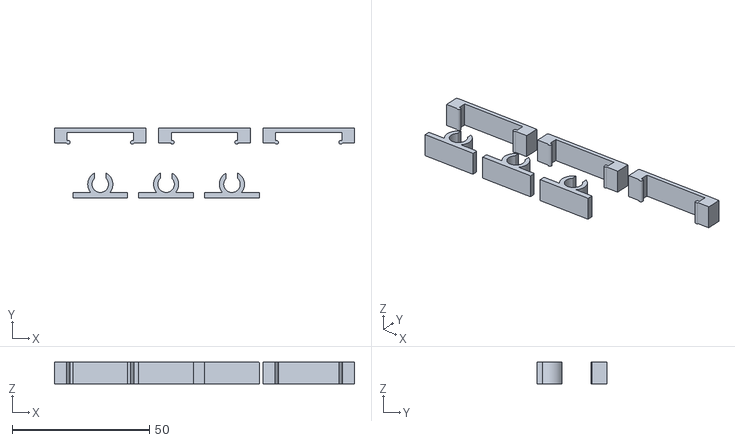
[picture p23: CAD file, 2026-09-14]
hardware/stl/cable_clip.stl
109.4 x 25.5 x 7.97

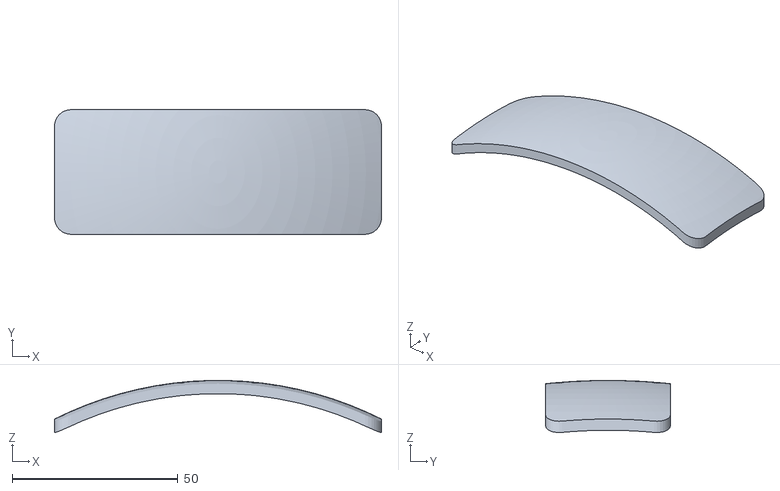
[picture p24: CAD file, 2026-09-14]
hardware/stl/worn/saddle_aux.stl
98.6 x 37.6 x 15.7

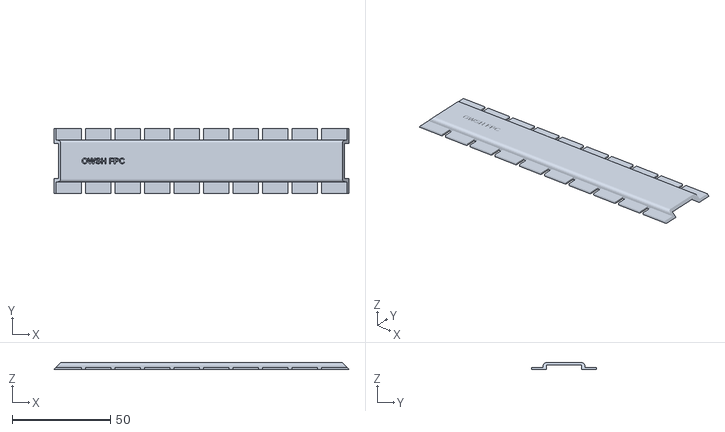
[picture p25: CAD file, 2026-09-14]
hardware/stl/fpc_cover.stl
150.0 x 33.2 x 3.40

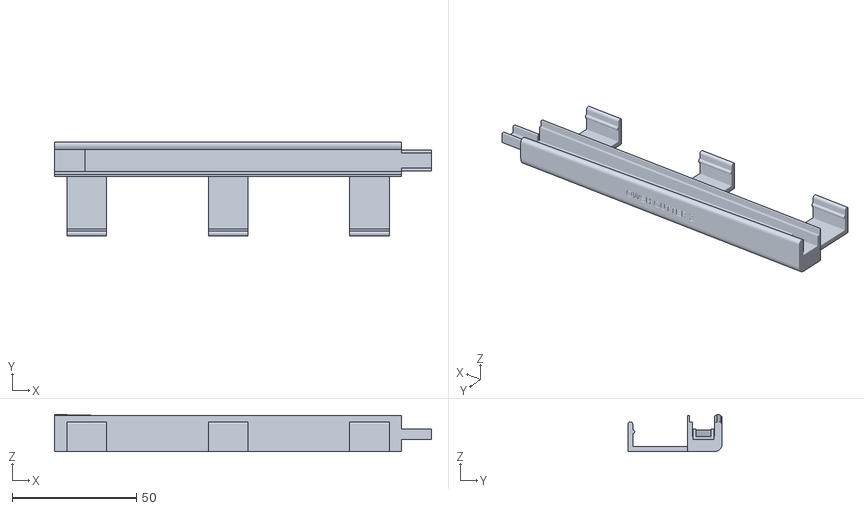
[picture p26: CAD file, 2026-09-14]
hardware/stl/worn/gutter_R2.stl
152.0 x 38.0 x 14.9

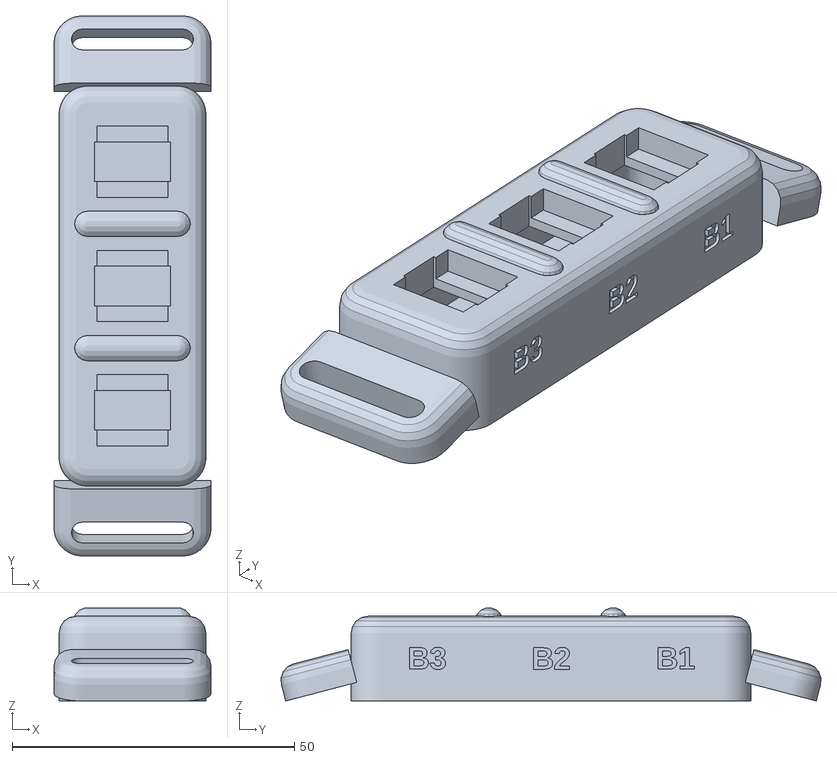
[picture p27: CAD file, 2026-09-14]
hardware/stl/button_module.stl
27.8 x 95.6 x 16.5

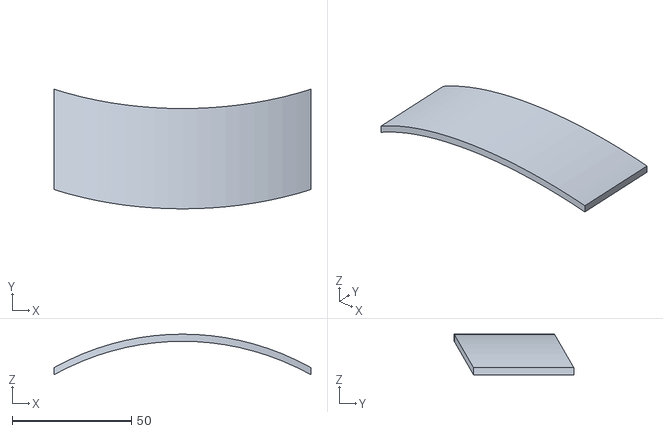
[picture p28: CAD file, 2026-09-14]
hardware/stl/worn/saddle_pod.stl
107.6 x 50.1 x 17.1

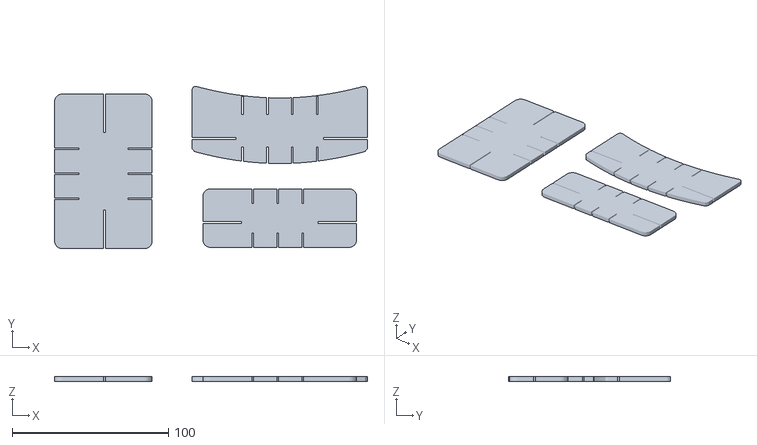
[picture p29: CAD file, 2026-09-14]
hardware/stl/saddle_pad.stl
200.5 x 104.0 x 3.00

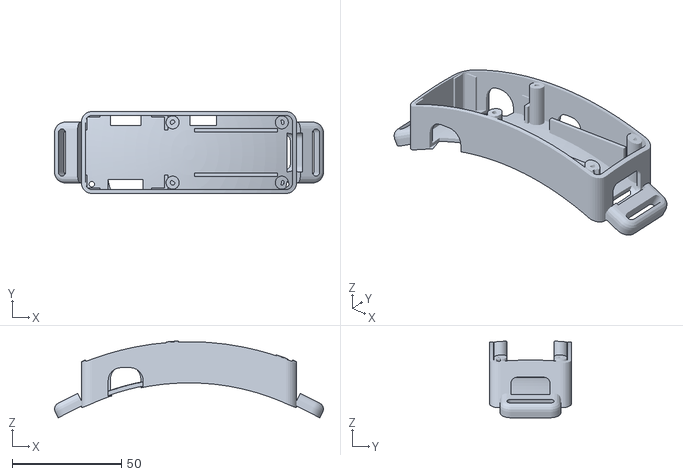
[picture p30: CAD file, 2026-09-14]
hardware/stl/worn/aux_pod_base.stl
123.2 x 37.6 x 35.1

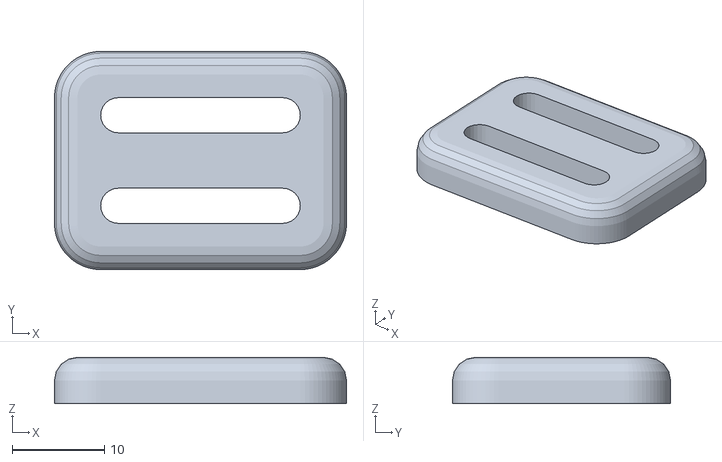
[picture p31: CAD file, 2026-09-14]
hardware/stl/strap_anchor.stl
31.6 x 23.6 x 5.00

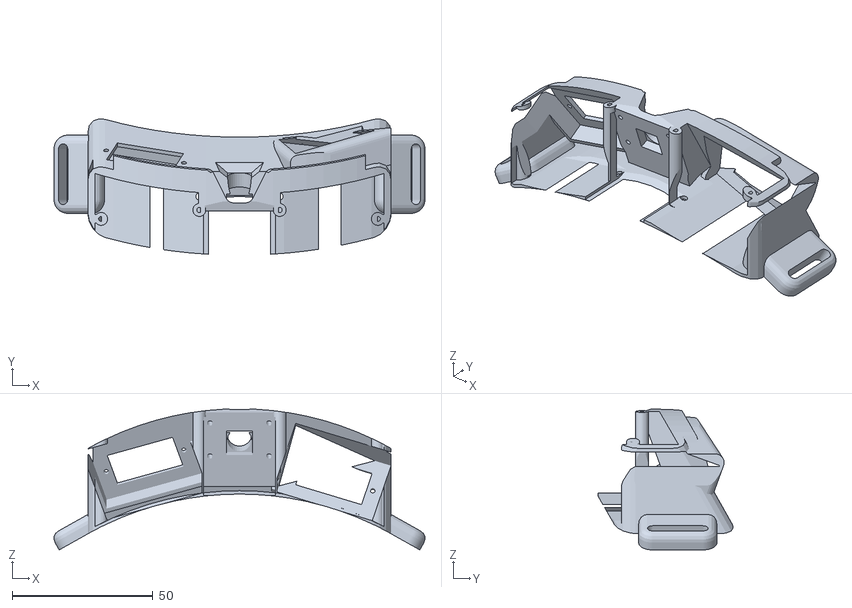
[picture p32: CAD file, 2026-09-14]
hardware/stl/worn/front_pod_base.stl
131.9 x 48.2 x 50.1

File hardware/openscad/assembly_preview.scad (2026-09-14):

// SPDX-License-Identifier: CERN-OHL-P-2.0
// Copyright 2026 CLSOFTLAB (씨엘소프트랩), Dr. Lee Il-guk (이일국)
// Open Walking Safety Helmet (OWSH) - assembly_preview (spec §10, §4.3; v1.1). NOT PRINTED.
// All modules on a helmet envelope of a typical adult M/L bicycle helmet: 270 L x 210 W x 155 H mm.
// The envelope is only a design stand-in: use a real certified helmet (P1).
// Modules are imported from hardware/stl/worn/*.stl (worn-frame exports written by the render
// scripts), so run scripts/render_all.* first. Beams: red = camera axis (10 deg down),
// green = forward LiDAR (horizontal), blue = down LiDAR (50 deg below horizontal).

use <lib/front_pod_lib.scad>
use <button_caps.scad>

W = "../stl/worn/";   // worn-frame STL folder (relative to this file)
P = "../stl/";

// ----------------------------------------------------------------- envelope
// Superellipsoid |x/a|^e + |y/b|^e + |z/c|^e = 1 (upper half). e = 2.35 gives crown radii of about
// 110-140 mm (spec §4.4: 95-130) so the conformal modules sit within 5 mm of the shell everywhere.
ha = 105; hb = 135; hc = 155; he = 2.35;
shell_t = 20;
show_helmet = true;
show_beams  = true;
show_gutter = true;

C_HELMET = [0.86, 0.86, 0.83, 0.6];
C_RIGID  = [0.18, 0.38, 0.68];
C_LID    = [0.30, 0.52, 0.82];
C_TPU    = [0.12, 0.12, 0.12];
C_BTN    = [0.95, 0.65, 0.10];
C_GUTTER = [0.10, 0.55, 0.45];

function spow(v, p) = (v < 0 ? -1 : 1) * pow(abs(v), p);
function se_z(x, y, a = ha, b = hb, c = hc) = c * pow(max(0, 1 - pow(abs(x) / a, he) - pow(abs(y) / b, he)), 1 / he);
function se_x(y, z, a = ha, b = hb, c = hc) = a * pow(max(0, 1 - pow(abs(y) / b, he) - pow(abs(z) / c, he)), 1 / he);
function e_pt(x, y) = [x, y, se_z(x, y)];
function e_n(p, a = ha, b = hb, c = hc) = let(v = [spow(p[0], he - 1) / pow(a, he), spow(p[1], he - 1) / pow(b, he), spow(p[2], he - 1) / pow(c, he)]) v / norm(v);
function unit(v) = v / norm(v);

// place a module frame: origin at point o, local X along (x projected on the tangent plane), Z along n
module frame(o, n, xdir) {
    X = unit(xdir - (xdir * n) * n); Y = cross(n, X);
    multmatrix([[X[0], Y[0], n[0], o[0]], [X[1], Y[1], n[1], o[1]], [X[2], Y[2], n[2], o[2]], [0, 0, 0, 1]]) children();
}
module on_shell(p, xdir, lift = 3) let(n = e_n(p)) frame(p + lift * n, n, xdir) children();

module superellipsoid(a, b, c, nu = 96, nv = 28) {
    pts = concat([for (k = [0 : nv - 1], j = [0 : nu - 1]) let(v = k * 90 / nv, u = j * 360 / nu)
                    [a * spow(cos(v), 2 / he) * spow(cos(u), 2 / he), b * spow(cos(v), 2 / he) * spow(sin(u), 2 / he), c * spow(sin(v), 2 / he)]],
                 [[0, 0, c]]);
    T = nv * nu;
    faces = concat([[for (j = [0 : nu - 1]) j]],
        [for (k = [0 : nv - 2], j = [0 : nu - 1]) [k * nu + j, (k + 1) * nu + j, (k + 1) * nu + (j + 1) % nu, k * nu + (j + 1) % nu]],
        [for (j = [0 : nu - 1]) [T, (nv - 1) * nu + (j + 1) % nu, (nv - 1) * nu + j]]);
    polyhedron(pts, faces);
}
module helmet() color(C_HELMET) difference() {
    superellipsoid(ha, hb, hc);
    translate([0, 0, -0.5]) superellipsoid(ha - shell_t, hb - shell_t, hc - shell_t);
    for (x = [-50, -17, 17, 50]) translate([x, 0, 0]) rotate([0, x / 3, 0]) hull() for (y = [-30, 20]) translate([0, y, 100]) cylinder(d = 10, h = 80, $fn = 16);
    for (x = [-75, 75]) translate([x, 30, 0]) rotate([0, x / 1.6, 0]) hull() for (y = [-20, 20]) translate([0, y, 70]) cylinder(d = 9, h = 80, $fn = 16);
    for (x = [-35, 35]) translate([x, -100, 0]) rotate([-50, 0, 0]) hull() for (xx = [-10, 10]) translate([xx, 0, 60]) cylinder(d = 9, h = 80, $fn = 16);
}

// ----------------------------------------------------------------- front pod (front-top)
pod_pitch = pod_mount_pitch();
function slope_at(y) = let(n = e_n(e_pt(0, y))) atan2(abs(n[1]), n[2]);
function find_slope(target, lo, hi, it = 40) = it == 0 ? (lo + hi) / 2 :
    let(mid = (lo + hi) / 2) slope_at(mid) < target ? find_slope(target, mid, hi, it - 1) : find_slope(target, lo, mid, it - 1);
pod_y = find_slope(pod_pitch, 1, hb * 0.95);
pf = pod_footprint();

module front_pod_on_helmet() on_shell(e_pt(0, pod_y), [1, 0, 0]) translate([0, -pf[1] / 2, 0]) {
    color(C_TPU) import(str(W, "saddle_pod.stl"));
    color(C_RIGID) import(str(W, "front_pod_base.stl"));
    color(C_LID) import(str(W, "front_pod_cover.stl"));
    if (show_beams) {
        sf = pod_sensor_frames();
        for (i = [0 : 2]) translate([sf[i][0], sf[i][1], sf[i][2]]) rotate([-sf[i][3], 0, 0])
            color([[1, 0, 0], [0, 0.8, 0], [0, 0.3, 1]][i]) rotate([-90, 0, 0]) cylinder(d = 1.5, h = [70, 160, 140][i], $fn = 8);
    }
}

// ----------------------------------------------------------------- main case (rear-top, long axis front-back)
case_y = -45;
module main_case_on_helmet() on_shell(e_pt(0, case_y), [1, 0, 0]) {
    color(C_TPU) import(str(W, "saddle_case.stl"));
    color(C_RIGID) import(str(W, "main_case_base.stl"));
    color(C_LID) import(str(W, "main_case_lid.stl"));
}

// ----------------------------------------------------------------- aux pod (back of the head)
aux_y = -118;
module aux_pod_on_helmet() on_shell(e_pt(0, aux_y), [1, 0, 0]) {
    color(C_TPU) import(str(W, "saddle_aux.stl"));
    color(C_RIGID) import(str(W, "aux_pod_base.stl"));
    color(C_LID) import(str(W, "aux_pod_lid.stl"));
}

// ----------------------------------------------------------------- button module (right side, above the ear)
module buttons_on_helmet() {
    p = [se_x(5, 45), 5, 45];
    n = e_n(p);
    frame(p + 1 * n, n, [0, 0, -1]) {     // module +Y stays world forward
        color(C_RIGID) import(str(P, "button_module.stl"));
        for (i = [0 : 2]) translate([0, [22, 0, -22][i], 15 + 1.3]) color(C_BTN) button_cap(["circle", "triangle", "square"][i], i + 1);
    }
}

// ----------------------------------------------------------------- haptic pads (inside, on comfort pads)
module pads_inside() {
    ia = ha - shell_t - 8; ib = hb - shell_t - 8; ic = hc - shell_t - 8;
    for (d = [[-1, 0.45, 0.30], [0, 0, 0.30], [1, 0.45, 0.30]]) {
        z = d[2] * ic;
        p = (d[0] == 0) ? [0, se_x(0, z, ib, ia, ic), z] : [d[0] * se_x(d[1] * ib, z, ia, ib, ic), d[1] * ib, z];
        n = e_n(p, ia, ib, ic);
        frame(p - 5.5 * n, n, [0, 0, 1]) color(C_TPU) import(str(P, "haptic_pad.stl"));
    }
}

// ----------------------------------------------------------------- rain gutter, bent along the rim
seg_len = 140; overlap = 12; nozzle_len = 70; clip_floor = 2; n_slices = 7;
function rim_pt(t) = [ha * spow(cos(t), 2 / he), hb * spow(sin(t), 2 / he)];
function chord_t(t0, L, lo, hi, n = 40) = n == 0 ? (lo + hi) / 2 :
    let(mid = (lo + hi) / 2) norm(rim_pt(mid) - rim_pt(t0)) < L ? chord_t(t0, L, mid, hi, n - 1) : chord_t(t0, L, lo, mid, n - 1);
function chain(t0, step, n) = n == 0 ? [t0] : concat([t0], chain(chord_t(t0, step, t0, t0 + 60), step, n - 1));
t_noz = -acos(pow((nozzle_len / 2) / ha, he / 2));
ts = chain(t_noz, seg_len / n_slices, 2 * n_slices);

module gutter_right() for (seg = [0, 1], j = [0 : n_slices - 1]) {
    // seg 1 (rear) spans chain points 0..n, seg 0 (front) spans n..2n; local x decreases toward the rear point
    base = (seg == 1) ? 0 : n_slices;
    Pr = rim_pt(ts[base + j]); Pf = rim_pt(ts[base + j + 1]);
    x1 = seg_len - j * seg_len / n_slices; x0 = x1 - seg_len / n_slices;
    d = Pr - Pf;
    translate([Pf[0], Pf[1], -clip_floor]) rotate([0, 0, atan2(d[1], d[0])])
        intersection() {
            translate([-x0, 0, 0]) import(str(W, seg == 1 ? "gutter_R2.stl" : "gutter_R1.stl"));
            translate([0, -60, -5]) cube([(x1 - x0) + (j == 0 ? overlap + 1 : 0.2), 120, 60]);
        }
}
module gutter_on_helmet() color(C_GUTTER) {
    gutter_right();
    mirror([1, 0, 0]) gutter_right();
    translate([0, rim_pt(t_noz)[1], -clip_floor]) rotate([0, 0, 180]) import(str(P, "rain_nozzle_rear.stl"));
}

// ----------------------------------------------------------------- FPC cover path (pod -> case)
module fpc_path() color(C_RIGID) {
    ys = [for (k = [0 : 8]) pod_y - 25 + (case_y + 52 - (pod_y - 25)) * k / 8];
    for (k = [0 : 7]) hull() for (y = [ys[k], ys[k + 1]]) let(q = e_pt(-20, y))
        on_shell(q, [1, 0, 0], 0) translate([0, 0, 1.5]) cube([22, 1, 3], center = true);
}

echo(str("OWSH assembly: envelope 270 x 210 x 155 mm, pod at y=", pod_y, " (slope ", slope_at(pod_y), " deg)"));
if (show_helmet) helmet();
front_pod_on_helmet();
main_case_on_helmet();
aux_pod_on_helmet();
buttons_on_helmet();
pads_inside();
if (show_gutter) gutter_on_helmet();
fpc_path();

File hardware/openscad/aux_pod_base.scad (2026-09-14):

// SPDX-License-Identifier: CERN-OHL-P-2.0
// Copyright 2026 CLSOFTLAB (씨엘소프트랩), Dr. Lee Il-guk (이일국)
// Open Walking Safety Helmet (OWSH) - aux_pod_base (v1.1, new part). PETG/ASA. Holds D1 ULN2003 + A1 USB
// audio adapter on the back of the head. Parameters are in lib/aux_pod_lib.scad and lib/owsh_common.scad.
// Print as exported; enable supports from the build plate (only the curved underside / top needs them).

include <lib/aux_pod_lib.scad>

worn = false;   // true: export in the worn frame (used by assembly_preview)
if (worn) aux_pod_base(); else aux_pod_base_print();

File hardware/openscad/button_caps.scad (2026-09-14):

// SPDX-License-Identifier: CERN-OHL-P-2.0
// Copyright 2026 CLSOFTLAB (씨엘소프트랩), Dr. Lee Il-guk (이일국)
// Open Walking Safety Helmet (OWSH) - button_caps (spec §10, §7.2, P8): one set of three caps,
// distinguishable by touch alone:
//   B1 front  : CIRCLE   outline, raised circular edge,   1 raised dot
//   B2 middle : TRIANGLE outline (tip points forward),    2 raised dots
//   B3 rear   : SQUARE   outline, raised square edge,     3 raised dots
// Print: PETG, socket side on the bed (as exported), no supports.

include <lib/owsh_common.scad>

// ----------------------------------------------------------------- parameters
stem_shape   = "round"; // actuator of your 12 x 12 x 7.3 switch: "round" or "square" (verify)
stem_d       = 7.0;     // round actuator diameter incl. clearance (verify with calipers)
stem_sq      = 3.6;     // square stem size incl. clearance (for switches with a square stem)
socket_depth = 2.6;
cap_h        = 5.0;     // body height
ridge_h      = 1.0;     // raised tactile edge height
dot_r        = 1.1;     // raised dots (hemispheres)
dot_pitch    = 2.8;
circle_d     = 16;
square_s     = 15;
tri_r        = 11.5;    // triangle circumradius (keeps it inside the 22 mm button pitch)

module shape2d(kind, inset = 0) {
    if (kind == "circle") circle(d = circle_d - 2 * inset, $fn = 64);
    else if (kind == "square") rounded_rect2d([square_s - 2 * inset, square_s - 2 * inset], max(0.8, 2 - inset));
    else // triangle, bounding box centred on the stem, tip toward +Y
        translate([0, -tri_r / 4, 0]) offset(r = 1) offset(delta = -1 - inset)
            rotate(90) circle(r = tri_r, $fn = 3);
}

// soft-edged solid of a 2D convex shape
module soft_extrude(kind, h, edge = 1.5) {
    hull() {
        linear_extrude(h - edge) shape2d(kind, 0);
        translate([0, 0, h - edge]) linear_extrude(edge * 0.5) shape2d(kind, edge * 0.35);
        translate([0, 0, h - eps]) linear_extrude(eps) shape2d(kind, edge);
    }
}

module tactile_ridge(kind) {
    difference() {
        hull() {
            linear_extrude(eps) shape2d(kind, 1.5);
            translate([0, 0, ridge_h]) linear_extrude(eps) shape2d(kind, 1.8);
        }
        hull() {
            translate([0, 0, -eps]) linear_extrude(eps) shape2d(kind, 2.8);
            translate([0, 0, ridge_h + eps]) linear_extrude(eps) shape2d(kind, 2.5);
        }
    }
}

module button_cap(kind, dots) {
    yc = (kind == "triangle") ? -tri_r / 4 : 0;   // dots at the triangle centroid
    difference() {
        union() {
            soft_extrude(kind, cap_h);
            translate([0, 0, cap_h - 0.2]) tactile_ridge(kind);
            for (i = [0 : dots - 1]) translate([(i - (dots - 1) / 2) * dot_pitch, yc, cap_h - 0.3])
                intersection() { sphere(r = dot_r, $fn = 16); cylinder(r = dot_r, h = dot_r); }
        }
        // stem socket
        translate([0, 0, -eps]) {
            if (stem_shape == "round") cylinder(d = stem_d, h = socket_depth, $fn = 32);
            else linear_extrude(socket_depth) square(stem_sq, center = true);
        }
    }
}

translate([-22, 0, 0]) button_cap("circle", 1);
translate([0, 0, 0])   button_cap("triangle", 2);
translate([22, 0, 0])  button_cap("square", 3);

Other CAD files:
hardware/stl/worn/main_case_lid.stl
hardware/stl/main_case_base.stl
hardware/stl/worn/front_pod_cover.stl
hardware/stl/aux_pod_base.stl
hardware/openscad/aux_pod_lid.scad
hardware/openscad/button_module.scad
hardware/openscad/cable_clip.scad
hardware/openscad/fpc_cover.scad
hardware/openscad/front_pod_base.scad
hardware/openscad/front_pod_cover.scad
hardware/openscad/haptic_pad.scad
hardware/openscad/main_case_base.scad
hardware/openscad/main_case_lid.scad
hardware/openscad/rain_gutter_segment.scad
hardware/openscad/rain_nozzle_rear.scad
hardware/openscad/saddle_pad.scad
hardware/openscad/strap_anchor.scad
hardware/stl/aux_pod_lid.stl
hardware/stl/button_caps.stl
hardware/stl/front_pod_base.stl
hardware/stl/haptic_pad.stl
hardware/stl/rain_gutter_segment.stl
hardware/stl/rain_nozzle_rear.stl
hardware/stl/worn/aux_pod_lid.stl
hardware/stl/worn/gutter_R1.stl

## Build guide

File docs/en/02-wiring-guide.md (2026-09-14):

# 02 · Wiring Guide

> Part of the Open Walking Safety Helmet · Licensed CC BY 4.0 · © 2026 CLSOFTLAB, Dr. Lee Il-guk

This guide connects all electronics to the Raspberry Pi 5 **without soldering**. It uses Dupont
jumper wires, the TF-Luna's GH1.25 cable and a small splitter.

- Wiring diagram: [`hardware/wiring/wiring_diagram.svg`](../../hardware/wiring/wiring_diagram.svg) and the
  device-side table in [`hardware/wiring/pinout.md`](../../hardware/wiring/pinout.md)
- Authoritative pin map: [spec §4.2](00-system-design-spec.md#42-raspberry-pi-5-pin-map-bcm-numbering--authoritative)
- Parts and refs (S1, D1, B1 …): [01 · Bill of materials](01-bill-of-materials.md)

> **Wire on the bench first.** Lay everything out on a table, wire it, and pass all checks in this
> guide. Only then move the parts into the printed cases ([04 · Assembly guide](04-assembly-guide.md)).

## Contents

1. [Safety rules for wiring](#1-safety-rules-for-wiring)
2. [Pin map (authoritative)](#2-pin-map-authoritative)
3. [Finding pins on the header](#3-finding-pins-on-the-header)
4. [Splitting shared lines without soldering](#4-splitting-shared-lines-without-soldering)
5. [Step-by-step wiring](#5-step-by-step-wiring)
6. [TF-Luna: I2C mode and address change](#6-tf-luna-i2c-mode-and-address-change)
7. [Checks](#7-checks)
8. [Common mistakes](#8-common-mistakes)

## 1. Safety rules for wiring

- **Unplug the power** before connecting or moving any wire. Remove the USB-C cable from the Pi.
- **Never put 5 V on a GPIO pin.** The Pi's GPIO pins are 3.3 V only. A 5 V signal can destroy the Pi.
- **Never connect 5 V or 3.3 V directly to GND.** Check twice before powering on.
- Handle the camera ribbon cable gently. Do not fold it sharply.
- Label every cable end as you go (for example "FWD SDA", "M1 L").

## 2. Pin map (authoritative)

This table is identical to spec §4.2. BCM numbering.

| Function | BCM GPIO | Header pin | Direction | Notes |
|---|---|---|---|---|
| I2C1 SDA | GPIO2 | 3 | bus | TF-Luna FWD 0x10, TF-Luna DOWN 0x11, MPU-6050 0x68 |
| I2C1 SCL | GPIO3 | 5 | bus | 400 kHz (`dtparam=i2c_arm=on,i2c_arm_baudrate=400000`) |
| Haptic LEFT | GPIO17 | 11 | out | → ULN2003 IN1 → M1 |
| Haptic CENTER | GPIO27 | 13 | out | → ULN2003 IN2 → M2 |
| Haptic RIGHT | GPIO22 | 15 | out | → ULN2003 IN3 → M3 |
| Button B1 (circle) | GPIO5 | 29 | in, pull-up | active-low |
| Button B2 (triangle) | GPIO6 | 31 | in, pull-up | active-low |
| Button B3 (square) | GPIO26 | 37 | in, pull-up | active-low |
| Status LED | GPIO16 | 36 | out | via 330 Ω |
| GPS TX→Pi RX (optional) | GPIO15 | 10 | in | UART0, 9600 baud |
| GPS RX←Pi TX (optional) | GPIO14 | 8 | out | |
| 5 V | — | 2, 4 | power | ULN2003 +, TF-Luna ×2 (5 V). **Never power button modules from 5 V** (5 V on a GPIO damages the Pi) |
| 3.3 V | — | 1, 17 | power | MPU-6050, button modules (**3.3 V required**; modules must be active-low, otherwise set `buttons.active_high: true` — an unconfigured active-high module reads as permanently pressed) |
| GND | — | 6, 9, 14, 20, 25, 30, 34, 39 | | Common ground |

> **Button modules: 3.3 V only.** If you use 3-pin button modules instead of bare switches, power them
> from pin 1 or 17. **Never from 5 V**: a module powered from 5 V puts 5 V on a GPIO pin and damages the Pi.

## 3. Finding pins on the header

- The 40-pin header has two rows. **Odd pins (1, 3, 5 …) are on the inner row.** Even pins (2, 4, 6 …)
  are on the row along the board edge.
- **Pins 1 and 2 are at the end farthest from the USB ports.** Pins 39 and 40 are next to the USB ports.
- On the Pi, run `pinout` in a terminal to print a diagram of the header.
- A printed GPIO reference card that slips over the pins helps a lot.

Pins used in this build (✔ = used, ○ = optional GPS or spare GND):

```
            inner row  outer row (board edge)
 3.3 V  ✔   1  ●  ●  2   ✔  5 V
 SDA    ✔   3  ●  ●  4   ✔  5 V
 SCL    ✔   5  ●  ●  6   ✔  GND
            7  ●  ●  8   ○  GPS RX←Pi TX (GPIO14)
 GND    ✔   9  ●  ●  10  ○  GPS TX→Pi RX (GPIO15)
 LEFT   ✔  11  ●  ●  12
 CENTER ✔  13  ●  ●  14  ✔  GND
 RIGHT  ✔  15  ●  ●  16
 3.3 V     17  ●  ●  18
           19  ●  ●  20  ✔  GND
           21  ●  ●  22
           23  ●  ●  24
 GND    ○  25  ●  ●  26
           27  ●  ●  28
 B1 ○   ✔  29  ●  ●  30  ✔  GND
 B2 △   ✔  31  ●  ●  32
           33  ●  ●  34  ✔  GND
           35  ●  ●  36  ✔  STATUS LED (GPIO16)
 B3 □   ✔  37  ●  ●  38
 GND    ✔  39  ●  ●  40
                 (USB ports this end)
```

## 4. Splitting shared lines without soldering

Some header pins must feed more than one device:

| Shared line | From header pin | Goes to |
|---|---|---|
| SDA | 3 | S1 pin 2, S2 pin 2, S3 SDA |
| SCL | 5 | S1 pin 3, S2 pin 3, S3 SCL |
| 5 V (sensors) | 2 | S1 pin 1, S2 pin 1 |
| 5 V (motors) | 4 | D1 "+", M1 +, M2 +, M3 + |
| GND (LiDARs) | 6 | S1 pin 4, S1 pin 5, S2 pin 4, S2 pin 5 |

Use part **W3** (spec §4.1), one of these:

- **Mini breadboard (170 tie-points).** Each half-column of 5 holes is one connected strip. Use one
  strip per shared line. Plug the wire from the Pi into the strip, then plug each device wire into
  the same strip. Label the strips: SDA, SCL, 5V-S, 5V-M, GND.
- **Dupont 1-to-N splitters, or a 2 × 8 female header splitter.** Smaller and easier to fit inside the
  cases. Wrap each splitter in heat-shrink tube or tape so it cannot touch other pins.
- **Do not use a Qwiic/STEMMA QT hub.** Those hubs carry 3.3 V only and use 1 mm JST-SH plugs; the TF-Luna needs 5 V.

For the final install on the helmet, splitters usually fit better than a breadboard. A mini breadboard
is handy for the bench build.

## 5. Step-by-step wiring

Each step lists every wire. Tick them off as you go.

### Step 1 · Prepare the splitter

1. Mark five strips (or five splitters): **SDA**, **SCL**, **5V-S** (sensors), **5V-M** (motors), **GND**.
2. Pi pin 3 → SDA strip.
3. Pi pin 5 → SCL strip.
4. Pi pin 2 → 5V-S strip.
5. Pi pin 4 → 5V-M strip.
6. Pi pin 6 → GND strip.

Ground pins used in this guide: pin 6 (GND strip), 9 (IMU), 14 (ULN2003), 20 (LED), 30 (B1),
34 (B2), 39 (B3). Pin 25 stays free as a spare.

### Step 2 · MPU-6050 IMU (S3, GY-521)

| GY-521 pin | Connect to |
|---|---|
| VCC | Pi pin 1 (3.3 V) |
| GND | Pi pin 9 (GND) |
| SCL | SCL strip |
| SDA | SDA strip |
| XDA, XCL, AD0, INT | leave unconnected |

AD0 unconnected keeps the address at 0x68.

### Step 3 · Forward TF-Luna (S1) — connect later for the address step

TF-Luna connector pins, counted from pin 1 as printed in the Benewake datasheet:

| TF-Luna pin | Name | Connect to |
|---|---|---|
| 1 | +5 V | 5V-S strip |
| 2 | SDA (RXD) | SDA strip |
| 3 | SCL (TXD) | SCL strip |
| 4 | GND | GND strip |
| 5 | Configuration | **GND strip.** This selects I2C mode. |
| 6 | Multiplexing output | leave unconnected |

> **Do not trust the wire colours.** Cable colours differ between batches. Count the pins on the
> connector using the pin-1 mark in the datasheet.

**Do not connect S1 yet.** First change the address of S2 ([section 6](#6-tf-luna-i2c-mode-and-address-change)).

### Step 4 · Down-looking TF-Luna (S2)

Wired exactly like S1:

| TF-Luna pin | Connect to |
|---|---|
| 1 +5 V | 5V-S strip |
| 2 SDA | SDA strip |
| 3 SCL | SCL strip |
| 4 GND | GND strip |
| 5 Configuration | GND strip |
| 6 | leave unconnected |

Put a label on S2: **DOWN 0x11**.

### Step 5 · ULN2003 driver (D1) and vibration motors (M1–M3)

On the helmet the ULN2003 sits in the **aux pod** at the back of the head, not in the main case.
Use Dupont wires long enough (about 20–30 cm) to reach from the Pi header to the aux pod.

The ULN2003 board has input pins IN1–IN4, two power pins "+" and "−", an ON/OFF jumper, and a
white 5-pin motor socket.

| ULN2003 pin | Connect to |
|---|---|
| IN1 | Pi pin 11 (GPIO17, LEFT) |
| IN2 | Pi pin 13 (GPIO27, CENTER) |
| IN3 | Pi pin 15 (GPIO22, RIGHT) |
| IN4 | leave unconnected |
| "+" | 5V-M strip |
| "−" | Pi pin 14 (GND) |
| ON/OFF jumper | **must be fitted** |

Motors. Each motor has two leads. The ULN2003 switches the negative side.

| Motor | + lead | − lead |
|---|---|---|
| M1 left temple | 5V-M strip | ULN2003 OUT1 |
| M2 forehead centre | 5V-M strip | ULN2003 OUT2 |
| M3 right temple | 5V-M strip | ULN2003 OUT3 |

**Reaching OUT1–OUT3 without soldering:**

1. The outputs are in the white 5-pin socket. Board layouts differ, so find them with a multimeter.
   On the ULN2003 chip, **pin 16 is OUT1, pin 15 is OUT2, pin 14 is OUT3** (pin 1 is next to the notch
   or dot). Check continuity from each chip pin to the socket holes and mark them.
2. Push the male end of an M-F Dupont wire into each output hole. It should hold firmly.
3. Connect the motor's − lead to the female end. If your motors have bare leads, use motors with a
   2-pin connector, crimp Dupont ends onto the leads (crimping is not soldering), or use small
   lever-type wire connectors.
4. A coin ERM motor vibrates in either polarity. What matters is that it sits **between 5 V and
   an OUT pin**, never between 5 V and GND.

The firmware caps motor duty at 75 % (`haptics.max_duty`), because the driver gives about 4 V to
3 V motors. Do not raise it.

### Step 6 · Buttons (B1–B3)

**Bare 12 × 12 mm tactile switches (recommended).** A switch has four legs in two connected pairs.
Use two **diagonally opposite** legs. That pair always switches, whichever way the switch is turned.

| Button | Shape (cap) | One leg | Diagonal leg |
|---|---|---|---|
| B1 front | ○ circle | Pi pin 29 (GPIO5) | Pi pin 30 (GND) |
| B2 middle | △ triangle | Pi pin 31 (GPIO6) | Pi pin 34 (GND) |
| B3 rear | □ square | Pi pin 37 (GPIO26) | Pi pin 39 (GND) |

The firmware turns on the internal pull-up. Idle reads high, pressed reads low (active-low).

**3-pin button modules.** VCC → **3.3 V only** (pin 1 or 17, via splitter), **never 5 V**. GND → GND.
OUT → GPIO as above.

- Use modules that output **low when pressed** (active-low).
- An active-high module (high when pressed) reads as **permanently pressed** unless configured. That can
  look like B3 held down and start an SOS countdown. Spec §4.2 defines the setting
  `buttons.active_high: true` for such modules. Check that your firmware version's
  `firmware/config/default.yaml` lists it before relying on it; otherwise use active-low modules or bare
  switches.
- Check every button with [check 7.4](#74-buttons).

### Step 7 · Status LED (L1)

1. Pi pin 36 (GPIO16) → one end of the 330 Ω resistor.
2. Other end of the resistor → LED **long leg** (anode).
3. LED **short leg** (cathode) → Pi pin 20 (GND).

An LED module with a built-in resistor connects directly: S → pin 36, − → GND.
The LED sits under the light-pipe hole in `main_case_lid`. Use Dupont wires long enough to reach it.

### Step 8 · Camera (C1)

1. Power off.
2. On the Pi 5, gently lift the latch of the **CAM/DISP 0** connector.
3. Insert the 22-pin end of the cable straight and fully. Follow the official Raspberry Pi camera
   documentation for which side the contacts face.
4. Close the latch. Pull very lightly: the cable must not move.
5. Connect the 15-pin end to the camera module the same way.

A reversed cable usually just means the camera is not detected. Power off and turn it around.

### Step 9 · Audio (A1, A2, W4)

1. Plug the **10–15 cm USB-A extension (W4)** into a **USB 2.0 port** (black) of the Pi. Keep the blue
   USB 3 ports free. This reduces 2.4 GHz noise near Bluetooth.
2. Plug the USB audio adapter into the extension. On the helmet, the adapter sits in the aux pod.
3. Plug the headset into the adapter: headphone plug into the headphone jack, mic plug into the mic jack.

### Step 10 · Optional GPS (G1)

| GPS pin | Connect to |
|---|---|
| TX | Pi pin 10 (GPIO15, RX) |
| RX | Pi pin 8 (GPIO14, TX) |
| VCC | 3.3 V or 5 V as printed on your module |
| GND | Pi pin 25 (spare GND) |

Enable the serial port: `sudo raspi-config` → Interface Options → Serial Port →
login shell **No**, serial hardware **Yes**.

### Step 11 · Power

Leave the power bank disconnected until [check 7.1](#71-before-power-on). The Pi is powered through
its USB-C socket from the power bank, through the magnetic breakaway adapter (P2).

## 6. TF-Luna: I2C mode and address change

Both TF-Luna sensors leave the factory with I2C address **0x10**. Two devices on one bus cannot share
an address. So you change the down-looking unit to **0x11**, once. The sensor remembers it.

You need a working Raspberry Pi OS with the firmware installed
([04 · Assembly guide, part B](04-assembly-guide.md#part-b--software-setup)). The commands below run from
the `firmware` folder, which contains the virtual environment `.venv` made by the setup script.

1. **Power off.** Connect **only S2** (down-looking) as in step 4. S1 stays disconnected.
   Pin 5 must be on GND, otherwise the sensor stays in UART mode and does not appear on I2C.
2. Power on. Stop the helmet service so nothing else uses the bus:
   ```bash
   sudo systemctl stop owsh
   ```
3. Check that the sensor is visible at 0x10:
   ```bash
   i2cdetect -y 1
   ```
   You should see `10` (and `68` if the IMU is connected).
4. Change the address:
   ```bash
   .venv/bin/python -m owsh.tools.tfluna_addr --from 0x10 --to 0x11
   ```
   Add `--dry-run` first if you want to see the register writes without touching the bus.
5. **Power off completely** for 5 seconds, then power on again.
6. Run `i2cdetect -y 1` again. You should now see `11` instead of `10`.
7. Label S2 **DOWN 0x11** if you have not already done so.
8. Power off. Connect S1 (forward) as in step 3. Power on and continue with [check 7.2](#72-i2c-bus).

If you mix up the sensors later, it is easy to tell them apart: the one at 0x11 is DOWN.

## 7. Checks

### 7.1 Before power on

- [ ] No bare metal of a splitter or wire end touches another pin.
- [ ] With a multimeter on continuity: 5 V pin 2 to GND pin 6 does **not** beep.
- [ ] 3.3 V pin 1 to GND does **not** beep.
- [ ] Both TF-Luna pin 5 wires go to the GND strip.
- [ ] ULN2003 ON/OFF jumper is fitted.
- [ ] Button module VCC (if used) goes to 3.3 V, not 5 V.

### 7.2 I2C bus

If `i2cdetect` is missing, install it: `sudo apt install -y i2c-tools`.

```bash
i2cdetect -y 1
```

Expected output, with exactly these three addresses:

```
     0  1  2  3  4  5  6  7  8  9  a  b  c  d  e  f
00:                         -- -- -- -- -- -- -- --
10: 10 11 -- -- -- -- -- -- -- -- -- -- -- -- -- --
20: -- -- -- -- -- -- -- -- -- -- -- -- -- -- -- --
30: -- -- -- -- -- -- -- -- -- -- -- -- -- -- -- --
40: -- -- -- -- -- -- -- -- -- -- -- -- -- -- -- --
50: -- -- -- -- -- -- -- -- -- -- -- -- -- -- -- --
60: -- -- -- -- -- -- -- -- 68 -- -- -- -- -- -- --
70: -- -- -- -- -- -- -- --
```

- `10` = TF-Luna FWD (S1)
- `11` = TF-Luna DOWN (S2)
- `68` = MPU-6050 (S3)

What other results mean:

| You see | Likely cause |
|---|---|
| Only `10`, no `11` | S2's address was not changed, or S2 is not connected. Both sensors may be answering at 0x10. |
| Nothing at 10 or 11 | TF-Luna pin 5 not on GND (UART mode), no 5 V, or SDA/SCL swapped |
| `69` instead of `68` | GY-521 AD0 is connected to VCC. Disconnect it. |
| Every address shows a number | SDA or SCL shorted to GND or 3.3 V |
| `Error: Could not open file /dev/i2c-1` | I2C not enabled. Run the setup script, or `sudo raspi-config nonint do_i2c 0` and reboot. |
| Addresses appear and disappear | Loose Dupont wire, or long wires. See [common mistakes](#8-common-mistakes). |

### 7.3 Camera

```bash
rpicam-hello --list-cameras
```

You should see one camera with sensor `imx708_wide`.

### 7.4 Buttons

With the helmet service stopped, set the pull-ups and read the pins:

```bash
pinctrl set 5,6,26 ip pu
pinctrl get 5,6,26
```

- Not pressed: each line ends with `hi`.
- Hold B1 and run `pinctrl get 5` again: it must show `lo`. Repeat for B2 (6) and B3 (26).
- If a pin shows `lo` when **not** pressed, the switch is wired to the wrong legs or shorted. Fix this
  before first boot.
- If a module shows `lo` when idle and `hi` when pressed, it is **active-high**. Replace it with an
  active-low module or a bare switch, or configure `buttons.active_high: true` if your firmware supports it.
  Otherwise the firmware sees the button as permanently pressed, and B3 could start an SOS countdown.

### 7.5 Motors and LED

Start the service (`sudo systemctl start owsh`) or reboot. At boot the **ready** pattern runs:
**left → centre → right**, 100 ms each.

- Hold M1, M2 and M3 between your fingers. They must buzz in that order.
- If the order is wrong, swap the motor − wires on OUT1–OUT3. Do not change the pin map.
- The status LED should light while the helmet is running.

### 7.6 Audio

```bash
aplay -l
```

The USB audio adapter should be listed. After boot you should hear the start-up voice message in the headset.

## 8. Common mistakes

1. **TF-Luna pin 5 not grounded.** The sensor stays in UART mode and is invisible on I2C.
2. **Both TF-Lunas connected during the address change.** The tool may change the wrong one, or
   both. Always connect only S2 for that step.
3. **Trusting wire colours** on the TF-Luna cable. Count pins.
4. **Button module on 5 V.** Puts 5 V on a GPIO and damages the Pi. Use 3.3 V only.
5. **Active-high button module.** Reads as "permanently pressed" unless configured. Check with `pinctrl get`.
6. **Motor between 5 V and GND** instead of 5 V and OUT. The motor runs all the time and the Pi
   cannot control it.
7. **ULN2003 ON/OFF jumper missing.** Motors never run.
8. **Missing common ground.** Every module's GND must go to a Pi GND pin.
9. **Using the wrong numbering.** The pin map uses BCM GPIO numbers *and* physical header pins.
   GPIO17 is header pin 11, not pin 17.
10. **GY-521 AD0 tied high.** The IMU moves to 0x69 and firmware cannot find it.
11. **Long, loose I2C wires on the helmet.** The bus from the rear case to the front pod is 30–40 cm.
    Twist SDA together with a GND wire, and SCL with another GND wire. Push every Dupont connector fully
    home and wrap connector pairs with tape. If `i2cdetect` is still unstable, try
    `i2c_arm_baudrate=100000` in `/boot/firmware/config.txt` as a diagnostic, and report it in a
    [field test report](../../.github/ISSUE_TEMPLATE/field_test_report.yml). The spec value is 400 kHz.
12. **Audio adapter (or its W4 extension) in a blue USB 3 port.** It works, but can add 2.4 GHz noise near Bluetooth.
13. **Camera cable not fully inserted.** Camera not listed. Reseat both ends with the power off.

Next: [03 · 3D printing guide](03-3d-printing-guide.md)

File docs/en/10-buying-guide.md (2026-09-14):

> Part of the Open Walking Safety Helmet · Licensed CC BY 4.0 · © 2026 CLSOFTLAB, Dr. Lee Il-guk

# 10 · Buying guide (verified purchase links)

This guide helps first-time builders **buy the right parts the first time**. Part specifications are in
[01 · Bill of materials](01-bill-of-materials.md). Builders in Korea: see the Korean guide with local shop carts,
[10 · 구매가이드](../ko/10-구매가이드.md).

> [!IMPORTANT]
> - **Prices and stock were checked on 2026-09-15.** They change. Check again before ordering.
> - **✅ verified** = we opened the product page and confirmed the exact title and key spec / part number.
> - **🔍 search** = no single listing can be recommended; the link opens a search. Check the **"must have"** column.
> - Official manufacturer pages are the most stable links. If a shop link breaks, search the **part number**
>   (SC1224, SC1129, SC1148, TF-Luna …).
> - The project has no affiliate or sponsorship relationship with any seller.

## The 7 most common mistakes

1. **Camera:** buy **Camera Module 3 Wide** (Raspberry Pi part **SC1224**), not the standard (75°), NoIR or NoIR Wide
   variants. Shops often list all four on one page.
2. **Camera cable:** buy the **Pi 5 camera cable, 22-pin 0.5 mm to 15-pin 1 mm, 300 mm** (Raspberry Pi calls it
   "Standard–Mini", part **SC1129**). The Wide camera may ship with only a 15-to-15 pin (Pi 4) cable, and short
   cables won't reach. Display cables look similar and do not work.
3. **LiDAR:** the title must say **TF-Luna**. TFmini-S, TFmini Plus and TF02 are different, larger sensors.
4. **No Qwiic/STEMMA QT hub** for W3. Those hubs carry 3.3 V only with 1 mm JST-SH plugs, but the TF-Luna needs 5 V.
   Use Dupont female 1-to-N splitters.
5. **Power bank:** the output table must list **USB-C 5 V ⎓ 3 A**. Many "PD 20 W" banks give 3 A only at 9 V or
   higher, and the helmet will then warn about low power.
6. **Headset and audio adapter must match.** Most headsets have one **4-pole (TRRS) plug**. Buy an adapter with a
   4-pole combo jack, or split jacks plus a TRRS→2×TRS splitter. Adapters that only list "line in" may be too weak
   for a headset mic.
7. **ULN2003:** buy the **driver board**, not the bare "ULN2003AP" chip.

## Core parts

| Ref | Part | Official page | Verified seller listings (price, stock on 2026-09-15) | Must have |
|---|---|---|---|---|
| U1 | Raspberry Pi 5 (8 GB recommended, 4 GB works) | [raspberrypi.com](https://www.raspberrypi.com/products/raspberry-pi-5/) ✅ | [DigiKey 8GB SC1432](https://www.digikey.com/en/products/detail/raspberry-pi/SC1112/21658257) $175, in stock ✅ · [DigiKey 4GB SC1431](https://www.digikey.com/en/products/detail/raspberry-pi/SC1111/21658261) $110, backorder ✅ · [The Pi Hut](https://thepihut.com/products/raspberry-pi-5) £105.60 / £168 ✅ · [Adafruit 8GB](https://www.adafruit.com/product/5813) $200 ✅ | Check the RAM size on the listing (old part numbers SC1111/SC1112 now redirect to SC1431/SC1432) |
| U2 | Raspberry Pi Active Cooler | [raspberrypi.com](https://www.raspberrypi.com/products/active-cooler/) ✅ | [DigiKey SC1148](https://www.digikey.com/en/products/detail/raspberry-pi/SC1148/21658255) $5 ✅ · [The Pi Hut](https://thepihut.com/products/active-cooler-for-raspberry-pi-5) £4.80 ✅ · [Adafruit](https://www.adafruit.com/product/5815) $13.50 ✅ | Pi 5 only; Pi 4 heatsinks don't fit |
| U3 | microSD 32 GB A2 | [Raspberry Pi SD cards](https://www.raspberrypi.com/products/sd-cards/) ✅ | 🔍 [AliExpress search](https://www.aliexpress.com/w/wholesale-microsd-32gb-a2.html) | **A2** marking; buy a known brand from its official store |
| C1 | Camera Module 3 **Wide** | [raspberrypi.com](https://www.raspberrypi.com/products/camera-module-3/) ✅ | [DigiKey SC1224](https://www.digikey.com/en/products/detail/raspberry-pi/SC0874/17278644) $35 ✅ · [The Pi Hut (select "Wide-angle")](https://thepihut.com/products/raspberry-pi-camera-module-3) £33.60 ✅ · [Adafruit 5658](https://www.adafruit.com/product/5658) $38.50 ✅ | "Wide", 120°, **not NoIR** |
| C2 | Pi 5 camera cable 300 mm | [raspberrypi.com](https://www.raspberrypi.com/products/camera-cable/) ✅ | [DigiKey SC1129](https://www.digikey.com/en/products/detail/raspberry-pi/SC1129/21658260) $2 ✅ · [The Pi Hut](https://thepihut.com/products/camera-adapter-cable-for-raspberry-pi-5) £1.90 ✅ · [Adafruit 5819](https://www.adafruit.com/product/5819) $3.16 ✅ · [SparkFun PRT-26025](https://www.sparkfun.com/raspberry-pi-5-camera-cable-300mm.html) $6 ✅ | 22-pin 0.5 mm ↔ 15-pin 1 mm, **300 mm**, "CAMERA" printed |
| S1, S2 | Benewake TF-Luna LiDAR ×2 | [benewake.com](https://en.benewake.com/TFLuna/index.html) ✅ · [manual PDF](https://en.benewake.com/uploadfiles/2024/04/20240426135946148.pdf) ✅ | [DFRobot SEN0340](https://www.dfrobot.com/product-1995.html) $24.90, cable included ✅ · [Seeed 101990656](https://www.seeedstudio.com/TF-Luna-LiDAR-Module-Short-Range-Distance-Sensor-p-4561.html) $28.90 ✅ · [The Pi Hut (Waveshare)](https://thepihut.com/products/tf-luna-lidar-ranging-sensor) £24, sold out ✅ | Title says **TF-Luna**; 6-pin cable included or ordered separately |
| S3 | MPU-6050 IMU | — (chip is obsolete) | 🔍 [AliExpress GY-521](https://www.aliexpress.com/w/wholesale-gy-521-mpu6050.html) · genuine alternative: [Adafruit 3886](https://www.adafruit.com/product/3886) $12.95 ✅ (different board shape) | I2C address 0x68 |
| M1–M3 | Coin vibration motor 10 × 2.7 mm, 3 V ×3 | — | [Adafruit 1201 "Vibrating Mini Motor Disc"](https://www.adafruit.com/product/1201) $1.95 ✅ · 🔍 [AliExpress 1027](https://www.aliexpress.com/w/wholesale-1027-coin-vibration-motor-3v.html) | 10 mm diameter, 3 V, with leads |
| D1 | ULN2003 driver board | — | 🔍 [AliExpress](https://www.aliexpress.com/w/wholesale-uln2003-driver-board-28byj-48.html) | Board with pin headers (from 28BYJ-48 kits), not the bare chip |
| B1–B3 | 12 × 12 mm tactile switch ×3 | — | [SparkFun COM-09190](https://www.sparkfun.com/momentary-pushbutton-switch-12mm-square.html) $0.75 ✅ · [Adafruit 1119 (10-pack)](https://www.adafruit.com/product/1119) $2.50 ✅ · 🔍 [AliExpress 12×12×7.3](https://www.aliexpress.com/w/wholesale-12x12x7.3mm-tactile-switch.html) | Through-hole. Height varies (6 / 7.3 / 8 mm): the printed parts assume 7.3 mm — if different, adjust `sw_body_h` in `button_module.scad` and `stem_d` / `stem_shape` in `button_caps.scad` |
| A1 | USB audio adapter | — | [Adafruit 1475](https://www.adafruit.com/product/1475) $4.95 ✅ · [The Pi Hut](https://thepihut.com/products/usb-audio-adapter-works-with-raspberry-pi) £4.30 ✅ (both list the input as "line in" — may be weak for a mic) · 🔍 [AliExpress](https://www.aliexpress.com/w/wholesale-usb-audio-adapter-headphone-microphone.html) | Real **mic** input; jack type matches the headset |
| A2 | Wired open-ear / bone-conduction headset with mic | — | 🔍 [AliExpress](https://www.aliexpress.com/w/wholesale-wired-bone-conduction-headphones-microphone.html) | **Wired 3.5 mm**, mic, leaves ears open |
| P1 | USB-C PD power bank 10 000–20 000 mAh | — | 🔍 [AliExpress](https://www.aliexpress.com/w/wholesale-usb-c-pd-power-bank-20000mah.html) | Output table lists **5 V ⎓ 3 A** on USB-C; safety certification for your country |
| P2 | Magnetic breakaway USB-C | — | [Adafruit 5521 (120 W data + power, right angle)](https://www.adafruit.com/product/5521) $14.95 ✅ | Rated ≥ 3 A **and** data-capable; avoid charge-only tips. Adafruit 5524 tip does not fit 5521 |
| W1 | Dupont F-F jumpers + 6-pin 1.25 mm cable | — | [Adafruit 266 (40 × 150 mm)](https://www.adafruit.com/product/266) $3.95 ✅ · 🔍 [AliExpress GH1.25 6-pin to Dupont](https://www.aliexpress.com/w/wholesale-gh1.25-6pin-to-dupont-cable.html) | 20 cm or longer helps reach the front pod |
| W2 | 3M Dual Lock + 20 mm hook-and-loop straps | [3M Dual Lock SJ3560](https://www.3m.com/3M/en_US/p/d/b40072057/) ✅ | Buy **small retail packs** (DigiKey only sells industrial rolls, e.g. SJ3560 150 ft $1,409 — don't) | Genuine 3M; straps 20 mm wide |
| W3 | Dupont female 1-to-N splitters | — | 🔍 [AliExpress](https://www.aliexpress.com/w/wholesale-dupont-splitter-female.html) | Female ends; **not** a Qwiic hub |
| W4 | USB-A male→female extension 10–30 cm | — | 🔍 [AliExpress](https://www.aliexpress.com/w/wholesale-usb-a-male-female-extension-15cm.html) | USB 2.0, slim plugs |
| F1 | M2.5 standoffs/screws + M2 screws | — | [Adafruit 3299 M2.5 nylon kit](https://www.adafruit.com/product/3299) $16.95 ✅ (6 mm standoffs, no M2) | Also buy M2 × 5 and M2 × 8 screws |

Optional: **G1 u-blox NEO-M8N GPS** — [u-blox NEO-M8 series](https://www.u-blox.com/en/product/neo-m8-series) ✅ (marked NRND; NEO-M8M-0 recommended). Marketplace modules are often clones: 🔍 [AliExpress](https://www.aliexpress.com/w/wholesale-neo-m8n-gps-module.html).

Also needed: a **certified bicycle helmet** from a local shop (EN 1078 / CPSC 1203 / AS/NZS 2063 / KC, new, with vents)
and **PETG (or ASA) + TPU 95A** filament.

## Where to buy Raspberry Pi parts in your country

Use the official reseller finder: **https://www.raspberrypi.com/resellers/** (about 150 approved resellers in 60+ countries).
Every product page on raspberrypi.com also has a **Buy now** button that lists resellers near you.

## Approximate cost (USD, excluding shipping, taxes and printer)

| Build | Range |
|---|---:|
| Reference (Pi 5 8 GB) | **about $440–660** |
| Pi 5 4 GB | **about $370–590** |

## Unpacking checklist

- [ ] Raspberry Pi 5 with the RAM size you ordered; Active Cooler **SC1148**
- [ ] Camera box says **Camera Module 3 Wide**, not NoIR
- [ ] Camera cable: narrow 22-pin end + wide 15-pin end, "CAMERA" printed, ~300 mm
- [ ] LiDAR label **TF-Luna**, 6-pin connector, cable present
- [ ] ULN2003 is a **board**, not a chip
- [ ] Tactile switch height measured (for button caps)
- [ ] Power bank label shows **5 V ⎓ 3 A**
- [ ] Headset plug fits the audio adapter (with splitter if needed)

Found a broken link or a better local source? Open an [issue](https://github.com/clsoftlab-lang/open-walking-safety-helmet/issues) — it saves the next builder from the same mistake.

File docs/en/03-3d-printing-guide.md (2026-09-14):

# 03 · 3D Printing Guide

> Part of the Open Walking Safety Helmet · Licensed CC BY 4.0 · © 2026 CLSOFTLAB, Dr. Lee Il-guk

This guide covers printing the clip-on modules. All parts are parametric OpenSCAD models. They fit
a 220 × 220 × 250 mm FDM printer.

- OpenSCAD sources: [`hardware/openscad/`](../../hardware/openscad/)
- Ready-to-print STL files: [`hardware/stl/`](../../hardware/stl/)
- Preview images: [`hardware/renders/`](../../hardware/renders/)
- Measured sizes, masses and parameters: [`hardware/README.md`](../../hardware/README.md)
- Part list authority: [spec §10](00-system-design-spec.md#10-printable-parts-list-openscad-parametric)

> **Never 3D-print the helmet shell.** Only the add-on modules are printed. The protective helmet
> is always a certified, store-bought helmet (spec principle P1).

## Contents

1. [Parts to print](#1-parts-to-print)
2. [Measure your helmet first](#2-measure-your-helmet-first)
3. [Materials](#3-materials)
4. [Print settings and supports](#4-print-settings-and-supports)
5. [Orientation](#5-orientation)
6. [Heights and masses](#6-heights-and-masses)
7. [Post-processing and test fit](#7-post-processing-and-test-fit)
8. [Rendering STL files from OpenSCAD](#8-rendering-stl-files-from-openscad)
9. [Troubleshooting](#9-troubleshooting)

## 1. Parts to print

This table follows spec §10. STL files in `hardware/stl/` have the same base name as the `.scad` file.

| File | Part | Material | Qty | Notes |
|---|---|---|---|---|
| `front_pod_base.scad` | Front pod body with camera bay (10° down), forward LiDAR bay, down LiDAR bay (50°) | PETG/ASA | 1 | Rain lip above lenses, strap slots 21 × 3.2 mm, curved underside |
| `front_pod_cover.scad` | Rear cover with FPC and cable exit | PETG/ASA | 1 | |
| `main_case_base.scad` | Pi 5 case base with standoffs, IMU slot, vents | PETG/ASA | 1 | Openings for USB-C power, USB-A and cooler exhaust; curved, ribbed underside |
| `main_case_lid.scad` | Lid with LED light pipe hole and drip edge | PETG/ASA | 1 | |
| `aux_pod_base.scad` | Aux pod base: ULN2003 and USB audio adapter cradles | PETG/ASA | 1 | Curved underside, headset-jack opening |
| `aux_pod_lid.scad` | Aux pod lid | PETG/ASA | 1 | |
| `saddle_pad.scad` | Conformal 3 mm TPU saddles under pod, case and aux pod | TPU | 3 sheets on 1 plate | Flat sheets with relief slits that bend onto the shell |
| `button_module.scad` | Button housing for 3 × 12 mm switches | PETG | 1 | |
| `button_caps.scad` | Caps ○ △ □ with raised tactile edges | PETG | 1 set | ○ 1 dot, △ 2 dots, □ 3 dots |
| `haptic_pad.scad` | Coin-motor pad with Velcro recess | TPU | 3 | |
| `strap_anchor.scad` | 20 mm strap anchor / buckle | PETG | 4 | Slots 21 × 3.2 mm |
| `cable_clip.scad` | Cable clip for FPC cover and Dupont bundles | PETG | 6 | |
| `fpc_cover.scad` | Camera cable cover channel | PETG | 1 | |
| `rain_gutter_segment.scad` | Flow-channel segment (front high → rear low), clip-over-rim | TPU | 4 | Patent 112, optional |
| `rain_nozzle_rear.scad` | Rear nozzle collecting both sides | TPU | 1 | Patent 113, optional |
| `assembly_preview.scad` | Whole assembly on a helmet envelope (not printed) | — | — | For renders |

Notes:

- In the v1.1 hardware the ULN2003 and USB audio adapter moved from the main case to the **aux pod**
  on the back of the head. They did not fit under the main case height limit.
- The rain gutter and nozzle are **optional**. Together they weigh about 95 g, more than their 60 g budget.
  A lighter gutter is on the [roadmap](08-patent-and-roadmap.md#69-lighter-rain-gutter).
- **About `hardware/stl/worn/`:** these meshes are the parts rotated into the position they have **on the
  head**, used for the assembly preview. They are **not oriented for printing. Print only from
  `hardware/stl/`.**

**Suggested print order.** Print `button_caps` and one `strap_anchor` first. They are small and quick,
and they show whether your fit and settings work. Then measure the helmet (next section), render the
curved parts for it, and print them.

## 2. Measure your helmet first

The front pod, main case and aux pod have **curved undersides** that follow the shell. Each sits on a
uniform **3 mm TPU saddle**, with no stilts and no gap larger than 5 mm (spec P2). The curve is fixed when
you print, so **measure your helmet before printing** those parts. The design envelope is a local radius of
**95–130 mm** (spec §4.4).

### How to measure a shell radius

You need a straight ruler (or any straight edge) and calipers.

1. Put the ruler on the shell exactly where the module will sit.
2. Read the **chord length** `L` between the two points where the ruler touches the shell. For example, 100 mm.
3. Measure the **gap** `h` between the ruler's middle and the shell, straight down. For example, 11 mm.
4. Calculate: **R ≈ L² ÷ (8 × h)**. Example: 100² ÷ (8 × 11) ≈ **114 mm**.
5. Measure **across** the head (left to right) and **along** the head (front to back) at each location.
   The value along the head is usually larger.

The spec calls these two values `helmet_radius` (across) and `helmet_radius_long` (along). They exist as
shared defaults in [`hardware/openscad/lib/owsh_common.scad`](../../hardware/openscad/lib/owsh_common.scad).
**In the v1.1 models, each module has its own parameters, and those are what shape the part:**

| Parameter | File | Default | Measure |
|---|---|---|---|
| `pod_R` | `lib/front_pod_lib.scad` | 110 mm | Across the head, under the front pod |
| `mount_pitch_deg` | `lib/front_pod_lib.scad` | 30° | Slope of the shell under the pod, head level (phone inclinometer). Sensor angles are compensated. |
| `case_R_lat`, `case_R_long` | `lib/main_case_lib.scad` | 110 / 140 mm | Across / along, under the main case |
| `aux_R_lat`, `aux_R_long` | `lib/aux_pod_lib.scad` | 110 / 140 mm | Around / up the back of the head, under the aux pod |
| `side_R` | `button_module.scad` | 140 mm | Along the shell above the right ear |
| `saddle_t` | `lib/owsh_common.scad` | 3 mm | Saddle thickness (keep ≤ 4 mm) |
| `clr` | `lib/owsh_common.scad` | 0.3 mm | Fit clearance per side |

Override on the command line without editing files, for example:

```bash
openscad -D pod_R=114 -D mount_pitch_deg=25 -o hardware/stl/front_pod_base.stl hardware/openscad/front_pod_base.scad
```

Or edit the values at the top of the library file, then re-render. Re-render **both** parts of a module
(base and lid or cover) and the `saddle_pad` plate after changing a module's radii. If your radius is far
from the default, check the gap under the ends of the pod: a very different shell can leave gaps.

If a measurement is outside 95–130 mm across the head, the helmet is outside the design envelope. Choose a
rounder helmet, or check the fit very carefully and report it in an issue.

## 3. Materials

| Material | Use for | Why |
|---|---|---|
| **PETG** | Pod, case, aux pod, lids, button housing, caps, clips, strap anchors, FPC cover | Tough, slightly flexible, handles about 70–80 °C, easy to print |
| **ASA** | Same rigid parts (not anchors or caps), as an alternative | Best UV and heat resistance for daily outdoor use. Needs an enclosure and ventilation. |
| **TPU 95A** | Saddles, haptic pads, rain gutter, nozzle | Soft and grippy. Follows the helmet's curve. Comfortable against the head. Gives way under impact. |

### Why not PLA?

- **PLA softens at about 55–60 °C.** A helmet on a car seat or a sunny bench goes past that easily.
  The Pi case can warp, the camera angle can shift, and the forward LiDAR can tilt. That silently
  changes where the sensors look.
- PLA becomes brittle outdoors and can crack into sharp pieces.
- PETG, ASA and TPU cost about the same and avoid all of this.

### Colour

- **Light colours** (white, light grey, yellow) heat up less in the sun. That helps the Pi stay cool: the
  cooler has only about 1.2 mm clearance under the main case lid.
- **High-visibility yellow or orange** helps drivers and cyclists see the wearer.
- Use **matte, dark** material around the camera window if you can, to reduce reflections into the lens.

## 4. Print settings and supports

Reference settings (spec §10 and `hardware/README.md`):

| Setting | Rigid parts (PETG/ASA) | TPU parts |
|---|---|---|
| Layer height | 0.2 mm | 0.2 mm |
| Walls / perimeters | 4 | 3 |
| Infill | 25 % gyroid (button caps, clips, FPC cover: 100 %) | 15 % (saddles: 100 %) |
| Nozzle temperature | PETG 240 °C · ASA 250–260 °C | 220–235 °C |
| Bed temperature | PETG 80 °C · ASA 90–100 °C | 40–60 °C |
| Speed | normal | slow: 20–25 mm/s |
| Retraction | normal | none or very short |
| Cooling fan | PETG 30–50 % · ASA 0–20 % | 50–100 % |
| Bed adhesion | PETG: glue stick or textured PEI | Clean PEI |

### Supports

- **Curved undersides and curved lids need supports from the build plate only.** Tree or organic supports
  are recommended. They touch only the face that sits on the saddle, or the curved top that no one touches.
- This applies to `front_pod_base`, `front_pod_cover`, `main_case_base`, `main_case_lid`, `aux_pod_base`
  and `aux_pod_lid`. `button_module` needs tiny supports under its angled strap tabs.
- All other overhangs are ≤ 45°. Saddles, pads, anchors, clips, FPC cover, gutter and nozzle need no supports.
- **Keep supports out of strap slots.** Clean any support or elephant foot from the slots afterwards.

Tips:

- **TPU:** a direct-drive extruder works best. On Bowden printers, print very slowly.
- **ASA:** print in an enclosure, away from people, with ventilation. It gives off fumes.
- **Dry your filament.** Wet PETG and TPU string badly and make weak parts. 4–6 hours at 55–65 °C
  in a filament dryer is usually enough.
- Values beyond the spec are starting points. Your filament maker's recommendations come first.

## 5. Orientation

The STL files in `hardware/stl/` are **already exported in print orientation**. Import them as they are.

| Part | Orientation (as exported) | Supports |
|---|---|---|
| `front_pod_base` | worn way up | yes, build plate only (curved underside) |
| `front_pod_cover` | top face down | yes, under the curved top |
| `main_case_base` | floor down | yes, under the ribs |
| `main_case_lid` | top face down | yes, under the curved rim |
| `aux_pod_base` | floor down | yes, under the curved floor |
| `aux_pod_lid` | top face down | yes |
| `saddle_pad` | flat | none |
| `button_module` | floor down | tiny, under the angled tabs |
| `button_caps` | socket side down | none |
| `haptic_pad` | skin membrane down | none |
| `strap_anchor` | flat | none |
| `cable_clip` | lying on the side | none |
| `fpc_cover` | flat | none |
| `rain_gutter_segment` | upright | none |
| `rain_nozzle_rear` | upright | none |

Strength note: FDM parts are weakest between layers. Straps pull on strap slots and anchors, so those parts
have layers **parallel** to the strap pull. That is why anchors print flat.

## 6. Heights and masses

Spec P2 height limits above the shell: **front pod ≤ 35 mm**, **main case ≤ 40 mm** (a Pi 5 with Active
Cooler cannot fit lower), **all other modules ≤ 30 mm**. Measured from the exported meshes
(`hardware/README.md`, including the 3 mm saddle):

| Module | Footprint (mm) | Max height above shell | Printed mass (est.) |
|---|---|---|---|
| Front pod (base + cover) | 107.6 × 42 (132 incl. strap tabs) | 34.8 mm | ≈ 40 g PETG |
| Main case (base + lid) | 99.1 × 62.6 (87.5 across incl. tabs) | 39.8 mm (34.6 mm at the centre) | ≈ 52 g PETG |
| Aux pod (base + lid) | 98.6 × 37.6 (123 incl. tabs) | 23.4 mm | ≈ 30 g PETG |
| Saddles (pod / case / aux) | as above, 3.0 mm thick | — | ≈ 13 / 18 / 11 g TPU |
| Button module + caps | 26 × 71 (96 incl. tabs) | ≈ 21 mm with caps | ≈ 22 g PETG |
| Rain gutter (4 segments) + nozzle | — | — | ≈ 86 g + 9 g TPU |

Total added mass with electronics is about **330 g without the rain gutter** (budget ≤ 380 g), and about
425 g with it. Masses are estimates from mesh volume; check your slicer.

## 7. Post-processing and test fit

1. **Remove supports and brims.** Use flush cutters and a craft knife. Cut away from your hand.
2. **Clear the strap slots.** All strap slots are **21 × 3.2 mm**. A 20 mm hook-and-loop strap must slide
   through freely. Remove any support, string or elephant foot.
3. **Round every outside edge.** External edges must stay rounded (fillet ≥ 3 mm) with no sharp
   points (spec P2). Sand or file any sharp corner, burr or support scar.
4. **Screw holes.** By default the holes are pilots for self-tapping screws. Drive each screw in once, back it
   out, then assemble. Do not over-tighten PETG. For brass heat-set inserts, set `use_heat_set = true` in
   `lib/owsh_common.scad`, re-export, and press the inserts in at about 230 °C.
5. **Test-fit electronics before final assembly:**
   - Raspberry Pi 5 with Active Cooler on the standoffs in `main_case_base`, lid on. The cooler must not
     touch the lid.
   - MPU-6050 in its slot; the 3 mm LED pressed into the lid from inside.
   - ULN2003 in its cradle and the USB audio adapter on its rails in `aux_pod_base`.
   - Camera Module 3 Wide in the camera bay. The lens must sit centred behind the window.
   - Both TF-Luna sensors in their bays. **Nothing may cover the TF-Luna lens aperture**, including
     stray plastic or a rain lip that hangs too low.
   - Coin motors slid into the `haptic_pad` pockets from the side.
   - 12 mm switches in `button_module`, caps pressed on.
6. **Check the angles.** With the pod on the helmet and the head level, use a phone inclinometer to check that
   the down-LiDAR facet faces about 50° below horizontal and the camera about 10° down. Note the values for
   calibration ([04 · Assembly guide](04-assembly-guide.md#part-h--calibration)).
7. **Feel the caps.** Close your eyes and check you can tell ○ (1 dot), △ (2 dots) and □ (3 dots) apart by
   touch alone, quickly. If not, reprint the caps slower, with a smaller layer height.
8. **Do not glue printed parts to the helmet.** Parts attach with straps and Dual Lock only.

## 8. Rendering STL files from OpenSCAD

The committed STL files use the default parameters. You only need OpenSCAD if you change a parameter or
improve a part. OpenSCAD 2021.01 or newer is required.

1. Install OpenSCAD from openscad.org (Windows, macOS, Linux). On Debian/Ubuntu/Raspberry Pi OS:
   ```bash
   sudo apt-get install -y openscad
   ```
2. Render one part (from the repository root):
   ```bash
   openscad -o hardware/stl/strap_anchor.stl hardware/openscad/strap_anchor.scad
   ```
3. Render everything with the project scripts. They write `stl/<part>.stl`, `renders/<part>.png`, the worn-frame
   meshes in `stl/worn/`, three assembly views and `renders/render_log.txt`. A full run takes about 17 minutes.
   ```bash
   hardware/scripts/render_all.sh                  # everything
   hardware/scripts/render_all.sh front_pod_base   # one part
   ```
   On Windows:
   ```powershell
   powershell -ExecutionPolicy Bypass -File hardware\scripts\render_all.ps1
   ```
4. `-D worn=true` exports a part in its worn position. Those meshes are for previews only.

Component dimensions (Pi 5, Camera Module 3 Wide, TF-Luna and others) are also parameters, listed in spec §4.4
and marked "verify" in the library files. **Measure your own parts with calipers**: camera lens barrel, TF-Luna
holes and window, Pi 5 cooler footprint, USB stack and header heights, GY-521 thickness, ULN2003 board and audio
adapter size, switch actuator, coin motor and helmet rim thickness.

If you improve a part, commit both the `.scad` change and the re-rendered STL so people without CAD can print it.
See [CONTRIBUTING.md](../../CONTRIBUTING.md).

## 9. Troubleshooting

| Problem | Try |
|---|---|
| Gap under the ends of a pod or case | Re-measure the shell radii; set `pod_R` / `case_R_*` / `aux_R_*`; re-render |
| Support scars on the curved underside | Use tree supports from the build plate only; sand lightly; the saddle hides small marks |
| PETG strings between walls | Dry the filament, lower temperature by 5 °C, increase retraction slightly |
| PETG part stuck to smooth PEI | Use glue stick as a release layer or a textured sheet next time |
| TPU jams in the extruder | Slow down, reduce or disable retraction, loosen idler tension |
| Warped ASA corners | Enclosure, brim, higher bed temperature, no drafts |
| Strap does not slide through a slot | Clear support and elephant foot; file the slot |
| Parts too tight | Raise `clr` (for example 0.4) and re-render |
| Camera or LiDAR does not fit its bay | Measure the part; adjust the dimension parameter; re-render |
| Pi screw holes do not line up | Check the 58 × 49 mm hole pitch; check scale is 100 % |
| Cooler touches the lid | Check the cooler model and the `pi_cooler_rect` parameter; never run with the lid pressing on the fan |
| Caps hard to tell apart | Print caps slower, at 0.12 mm layers, with sharper raised edges and dots |

Next: [04 · Assembly guide](04-assembly-guide.md)

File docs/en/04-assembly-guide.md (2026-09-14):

# 04 · Assembly Guide

> Part of the Open Walking Safety Helmet · Licensed CC BY 4.0 · © 2026 CLSOFTLAB, Dr. Lee Il-guk

This guide takes you from a box of parts to a tested helmet. Plan for one or two days, not counting printing.

Read [06 · Safety](06-safety.md) before you start. The two most important rules:

1. **Never drill, cut, glue into or melt the helmet shell or its foam liner.** Everything attaches with
   straps through the vents and removable pads.
2. **The helmet assists. It never replaces the white cane, a guide dog or O&M training.**

## Contents

- [Part A — Preparation](#part-a--preparation)
- [Part B — Software setup](#part-b--software-setup)
- [Part C — Bench wiring and first checks](#part-c--bench-wiring-and-first-checks)
- [Part D — Building the modules](#part-d--building-the-modules)
- [Part E — Mounting on the helmet without drilling](#part-e--mounting-on-the-helmet-without-drilling)
- [Part F — Pairing the phone](#part-f--pairing-the-phone)
- [Part G — First boot test checklist](#part-g--first-boot-test-checklist)
- [Part H — Calibration](#part-h--calibration)
- [Part I — Before the first real walk](#part-i--before-the-first-real-walk)
- [Switching off and looking after the memory card](#switching-off-and-looking-after-the-memory-card)

---

## Part A — Preparation

- [ ] All parts from [01 · Bill of materials](01-bill-of-materials.md), including the W3 splitter and W4 USB extension.
- [ ] All printed parts from [03 · 3D printing guide](03-3d-printing-guide.md), cleaned and test-fitted, with the
      curved parts rendered for **your** helmet's measured radii.
- [ ] A computer with a microSD card reader and [Raspberry Pi Imager](https://www.raspberrypi.com/software/).
- [ ] Wi-Fi for setup (only needed to install software; the helmet works offline afterwards).
- [ ] An Android phone with Chrome (or an iPhone with the Bluefy browser) for the phone app.
- [ ] A kitchen scale. **Weigh the empty helmet now** and write the value down.
- [ ] Mild soap, water and a cloth to clean the helmet shell.

## Part B — Software setup

### B1. Flash Raspberry Pi OS Bookworm 64-bit

1. Insert the microSD card into your computer and open Raspberry Pi Imager.
2. **Device:** Raspberry Pi 5.
3. **Operating system:** *Raspberry Pi OS (64-bit)* based on **Debian 12 "Bookworm"**.
   If Imager's default is a newer release, open *Raspberry Pi OS (other)* and choose the Bookworm
   64-bit (Legacy) image. Firmware v1.0 is built and tested for Bookworm.
4. **Storage:** your microSD card.
5. **Edit settings** (OS customisation):
   - Hostname, for example `owsh-01`.
   - User name and a strong password. Write them down for the owner.
   - Wi-Fi network and country.
   - Time zone and keyboard layout.
   - Services: enable **SSH** (password or key).
6. Write the card, then put it in the Pi.

### B2. First start and update

1. Connect the Pi to a normal USB-C power supply (5 V 3 A or the official 27 W supply) for setup.
2. Wait 1–2 minutes, then connect from your computer: `ssh <user>@owsh-01.local`.
3. Update the system:
   ```bash
   sudo apt update && sudo apt full-upgrade -y
   sudo reboot
   ```

### B3. Install the firmware

1. Get the project and go to the `firmware` folder:
   ```bash
   sudo apt install -y git
   git clone <repository-url> owsh
   cd owsh/firmware
   ```
   Use the repository URL shown on the project's GitHub page.
2. Run the setup script **as your normal user** (not with `sudo`; it asks for your password when needed):
   ```bash
   bash scripts/setup_pi.sh          # add --ocr to also install text reading
   ```
   The script:
   - installs system packages (camera, GPIO, `espeak-ng`, `i2c-tools`, `bluez`, `bluez-tools`);
   - turns on I2C at 400 kHz and the camera in `config.txt`;
   - creates the virtual environment `firmware/.venv` and installs the firmware;
   - downloads the AI models and runs the self-tests;
   - installs and enables two services: **`owsh`** (the helmet firmware) and **`owsh-bt-agent`** (the
     Bluetooth pairing agent);
   - allows the helmet's safe-shutdown gesture to power off the Pi.
3. Reboot: `sudo reboot`.
4. Check the services:
   ```bash
   systemctl status owsh owsh-bt-agent
   journalctl -u owsh -f
   ```
   Without sensors connected you will see FAULT messages. That is expected and correct (spec P4):
   a missing sensor must never look like "all clear".

In this guide, firmware tools run from the `firmware` folder with the virtual environment's Python:
`.venv/bin/python -m owsh.tools.<tool>`.

**Text reading (OCR)** is optional (spec §5.5). If you did not use `--ocr`, pressing ○ says
"Text reading is not installed". To add it later: `.venv/bin/pip install -e ".[ocr]"`, then
`sudo systemctl restart owsh`.

**Try the simulator first (optional).** On any PC with a webcam you can run
`python -m owsh --sim` to learn the haptic patterns and buttons before the hardware is ready
(see [`firmware/README.md`](../../firmware/README.md)).

## Part C — Bench wiring and first checks

1. Power off. Wire everything on the table following [02 · Wiring guide](02-wiring-guide.md).
2. Change the down-looking TF-Luna's address to 0x11 ([wiring guide section 6](02-wiring-guide.md#6-tf-luna-i2c-mode-and-address-change)).
3. Pass all checks in [wiring guide section 7](02-wiring-guide.md#7-checks):
   `i2cdetect -y 1` shows `10`, `11`, `68`; the camera is listed; buttons read `hi`/`lo`; motors buzz
   left → centre → right at boot.

**Do not continue until the bench build passes every check.** Faults are far easier to find on a
table than inside a closed case on a helmet.

## Part D — Building the modules

Power off before each step. Screw sizes are listed in [`hardware/README.md`](../../hardware/README.md).
For self-tapping holes, drive each screw in once, back it out, then assemble.

### D1. Front sensor pod (`front_pod_base`, `front_pod_cover`)

1. Mount the **Camera Module 3 Wide** in the camera bay with 4 × M2 × 5 screws. The lens looks
   through the window, 10° down. Do not overtighten: the board can crack.
2. Connect the 15-pin end of the camera cable before closing anything.
3. Place **S1 (forward TF-Luna)** in the forward bay, lens facing forward (2 × M2 × 5).
4. Place **S2 (down TF-Luna, labelled 0x11)** in the 50° facet, lens facing down and forward (2 × M2 × 5).
5. **Do not cover the lenses.** Check from the front: both TF-Luna apertures and the camera lens are
   completely clear, and the rain visor does not hang into their view.
6. Route the camera ribbon and the two TF-Luna cables out through the cable exits in the rear wall.
7. Close `front_pod_cover` (4 × M2 × 8).
8. Clean the lenses with a microfibre cloth.

### D2. Main case (`main_case_base`, `main_case_lid`)

The main case holds only the **Pi 5 with Active Cooler, the MPU-6050 and the status LED**.

1. Fit the **Active Cooler** to the Pi 5 (follow the instructions in its box).
2. Mount the Pi on the standoffs with 4 × M2.5 × 6 screws. The USB-C power socket, the USB-A ports and the
   cooler exhaust must line up with their openings.
3. Slide the **MPU-6050** into its slot. Mount it firmly. Its orientation does not matter for fall detection
   (it uses total acceleration), but a loose IMU rattles and can look like an impact.
4. Press the 3 mm status LED into the lid from inside.
5. Connect the camera ribbon's 22-pin end to **CAM/DISP 0**.
6. Connect the Dupont wires as in the bench build. Keep the splitters wrapped. The wires to the ULN2003
   (IN1–IN3, 5 V, GND) leave the case toward the aux pod.
7. Plug the **W4 USB-A extension** into a black USB 2.0 port. Its socket end leaves through the rear opening.
8. Close the lid (4 × M2.5 × 8). No wire may be pinched. The cooler fan must spin freely; it has only about
   1.2 mm clearance to the lid.

### D3. Aux pod (`aux_pod_base`, `aux_pod_lid`)

The aux pod on the back of the head holds the **ULN2003 driver** and the **USB audio adapter**.

1. Put the ULN2003 board in its cradle. Connect IN1/IN2/IN3 (GPIO17/27/22), "+" (5 V) and "−" (GND) from the
   main case wires.
2. Connect the three motor leads to the ULN2003 as in the wiring guide. The motor leads leave through the
   **lower notch** toward the comfort pads.
3. Plug the USB audio adapter onto the W4 extension and slide it onto its rails. The headset jacks face the
   jack opening.
4. Close the lid (4 × M2.5 × 8).

### D4. Button module (`button_module`, `button_caps`)

1. Insert the three 12 mm switches.
2. Press on the caps in this order, from **front to back**: **○ circle, 1 dot (B1)**, **△ triangle, 2 dots (B2)**,
   **□ square, 3 dots (B3)**.
3. Connect the wires: B1 → GPIO5 (pin 29), B2 → GPIO6 (pin 31), B3 → GPIO26 (pin 37), each with its GND.
   Button modules, if used, get **3.3 V only**.
4. Check again by touch with your eyes closed: circle front, triangle middle, square rear.

### D5. Haptic pads (`haptic_pad` × 3)

1. Slide one coin motor into each TPU pad from the side. The skin membrane faces the head.
2. Stick a piece of the **hook** side of hook-and-loop into the recess.
3. Label the pads: **L** (M1), **C** (M2), **R** (M3).

## Part E — Mounting on the helmet without drilling

> **Rules for every step:**
> - No drilling, cutting, gluing into, heating or melting the shell or the foam liner.
> - Only straps through existing vents, removable Dual Lock pads on the **outer** shell surface,
>   and hook-and-loop on the **comfort padding**. Never replace straps with screws, zip ties or glue.
> - Height above the shell: front pod ≤ **35 mm**, main case ≤ **40 mm**, every other module ≤ **30 mm**.
>   All outside edges rounded. No stilts or gaps larger than 5 mm under a module.

### Where each module goes

| Module | Position |
|---|---|
| Front sensor pod | Front-top, centred, above the forehead |
| Main case | Top of the head, behind the crown, long side front-to-back |
| Aux pod | Back of the head, below the main case |
| Button module | Right side, above the ear, near the lower rim |
| Haptic pads | Inside, on the comfort pads: left temple, forehead centre, right temple |

### E1. Clean the shell

Wash the mounting areas with mild soap and water, then dry completely. **Do not use solvents** such as
acetone or strong alcohol: many helmet makers warn they can weaken the shell. Dual Lock sticks best above
15 °C and reaches full strength after about 24–72 hours.

### E2. Saddles

Each of the three large modules sits on its own 3 mm TPU saddle from the `saddle_pad` plate (pod, case, aux).

1. Put Dual Lock on **both faces** of each saddle (or hook-and-loop).
2. The saddle **only rests** on the shell and bends to its shape. Never glue it to the shell.

### E3. Front sensor pod

1. Press the pod onto its saddle.
2. Place it on the shell, centred left-to-right above the forehead. Look from the side: the forward LiDAR
   should be roughly horizontal when the helmet sits on a head in normal posture.
3. Thread **two 20 mm straps**: down through a strap tab slot, through a helmet vent, and back up. Close them
   **snug, not tight**.
4. Inside the helmet, each strap must lie **flat** against the liner with no twist or buckle on the head side.
   The comfort padding covers it.
5. Check the gap between the saddle and the shell at the pod's ends. If there is a gap larger than a few mm, the
   pod was rendered for a different radius. Re-measure and reprint.

### E4. Main case

Same method: saddle + Dual Lock + **two straps through vents**, on top of the head behind the crown, long side
front-to-back. The USB-C opening and cooler exhaust must not be blocked by a strap or the shell.

### E5. Aux pod

1. Saddle + Dual Lock + straps through the vents at the back of the head, below the main case.
2. Route the **W4 USB extension** and the ULN2003 wires from the main case's rear opening to the aux pod in a short,
   tidy loop. Hold them with `cable_clip`s. They must not hang free where a hand or branch could catch them.
3. The headset cable leaves the aux pod's jack opening and goes to the headset around the side of the helmet,
   not across the face.

### E6. Button module

1. Fix a `strap_anchor` through a side vent with a short strap.
2. Attach the button module with Dual Lock and its angled strap tabs.
3. Check with the user: they should find ○ at the front without searching, with the right hand.
4. The module must not press on the ear or catch on glasses or a hat.

### E7. Haptic pads

1. Put the **loop** side of hook-and-loop on the helmet's removable comfort pads: **left temple**,
   **forehead centre**, **right temple**. Most comfort pads are already a loop fabric that hook tape grips.
2. Press the pads on. Never glue them to the foam liner.
3. Let the user put the helmet on. Adjust the pad positions until each one is felt clearly and
   separately. Hair, headscarves and caps weaken vibration. Move the pads rather than increasing power.

### E8. Cable routing

1. Run the camera ribbon from the front pod to the main case inside `fpc_cover`, along the shell
   centre line, under the straps. Hold it with `cable_clip`s.
2. Bundle the TF-Luna and button Dupont wires along the same path. Twist each I2C line with a ground wire.
3. Motor leads go from the aux pod's lower notch through a vent to the inside. Route them along the edge of
   the liner, under the comfort padding, so they never touch the skin.
4. Leave small loops of slack at each module. A pulled cable must not pull a connector out.
5. Nothing may hang in front of the face, cross the ears, or pass under the chin strap.

### E9. Breakaway power cable

The power bank rides in a pocket or waist bag. The cable must never be able to catch around the neck.

1. Plug the **magnetic breakaway adapter** into the Pi's USB-C socket (or put it at the point where
   the cable leaves the helmet).
2. Route the 1.5 m cable from the rear of the helmet down the back to the pocket or waist bag.
3. **Pull test:** with the helmet on a table, pull the cable sharply. The magnetic joint must separate
   before the helmet moves. If the helmet slides instead, the adapter holds too hard. Replace it.
4. Never wrap the cable around the neck or through clothing in a way that could tighten.

### E10. Final mechanical checks

- [ ] **Height above the shell** (calipers at the highest point): front pod ≤ 35 mm, main case ≤ 40 mm,
      aux pod, button module and everything else ≤ 30 mm.
- [ ] **No gap larger than 5 mm** between any module's saddle and the shell.
- [ ] **Mass:** weigh the helmet again. Added mass without power bank and without rain gutter is **≤ 380 g**
      (expected about 330 g).
- [ ] **Balance:** the helmet does not tip forward or back on the head when the user nods.
- [ ] **Fit:** the helmet still sits level and the chin strap and fit dial adjust normally.
- [ ] **No drilling, cutting or glue** in the shell or liner. Check this again.
- [ ] **Edges:** run a hand over every module. No sharp corners, points or loose wire ends.
- [ ] **Ventilation:** at least some vents stay open.
- [ ] **Certification label** inside the helmet is still readable.

## Part F — Pairing the phone

The helmet only accepts commands from a **paired (bonded) phone**, over an encrypted link (spec §8.3).
Otherwise anyone nearby could mute it or lower the drop-off sensitivity.

1. Open the phone app over HTTPS in Chrome on Android, or in the Bluefy browser on iPhone
   (see [`app/README.md`](../../app/README.md)).
2. Switch the helmet on. While **no phone is paired yet**, pairing is always open. Once a phone is paired,
   pairing is open only for the **first 2 minutes after each start**.
3. In the app tap **Connect** and choose `OWSH-XXXX`.
4. When the app first sends a command, the phone shows its normal system dialog, for example
   **"Pair with OWSH-XXXX?"**. There is no PIN, because the helmet has no screen or keypad. Tap **Pair**.
   Screen readers read this dialog aloud.
5. The helmet says **"New phone paired: <phone name>."** Later connections are automatic.
6. **To add or replace a phone,** restart the helmet and pair within 2 minutes.
7. **To remove all pairings,** on the Pi run `bluetoothctl devices Paired`, then
   `bluetoothctl remove <address>` for each device.

Tell the user: if the helmet ever says "New phone paired" when they did not pair a phone, someone else paired.
Remove the pairings and restart the helmet.

## Part G — First boot test checklist

Do this indoors, in a safe room, with a sighted helper. Watch the log from a laptop:
`journalctl -u owsh -f`. Tick each item. Voice messages are quoted from the English phrase file
(`firmware/owsh/i18n/en.json`).

### G1. Start-up

- [ ] Connect the power bank. The status LED lights.
- [ ] Within about a minute the headset says "Helmet ready." and "This helmet only assists. Keep using your
      cane or guide dog."
- [ ] **Ready pattern:** a quick sweep **left → forehead → right** (100 ms each).
- [ ] No FAULT pattern (three very quick forehead buzzes) follows. If it does, check the log.

### G2. Buttons (every accepted press gives a short `tick` on the forehead)

- [ ] ○ B1 short (under 0.8 s): tick, then text reading (or "Text reading is not installed.").
- [ ] ○ B1 long (1.5 s or more): tick, the last message is repeated.
- [ ] A press between about 0.8 s and 1.5 s is ignored.
- [ ] △ B2 short: tick, scene description.
- [ ] △ B2 long: tick, "where am I" (needs the phone app connected).
- [ ] △ B2 double: tick, who is here (faces).
- [ ] □ B3 short: tick, status report.
- [ ] □ B3 double: tick, "Voice info muted. Warnings are still spoken." Then press △ B2 short: the scene
      description is **still spoken**, because it answers your own button press. Double-press □ again to unmute.
- [ ] □ B3 hold 3 s: the SOS countdown starts while you are still holding (all three motors pulse once per
      second, voice warns). **Press any button to cancel.** Check it cancels. Do the full SOS test later
      ([07 · Test plan](07-test-plan.md) T9).

### G3. Safe shutdown

- [ ] Press ○ B1 and □ B3 **together** (within about 1 s of each other) and hold both for **5 s**.
- [ ] The helmet says "Shutting down.", the ready pattern runs in reverse (**right → forehead → left**), and the
      Pi powers off about 3 s later. The status LED goes out.
- [ ] No SOS countdown started and the last message was not repeated.
- [ ] Switch on again (unplug and replug the power). Now hold both buttons and **let go of one after about 2 s**:
      nothing happens (the shutdown is cancelled, no SOS).

### G4. Forward LiDAR zones (use your hand or a book)

The forward beam is narrow (2°): about 7 cm wide at 2 m. Hold the target straight ahead of the pod,
at head height. A book or a board is easier to hit than a hand.

- [ ] Target at about **1.8 m**: slow, gentle forehead pulses (`zone3`). No voice.
- [ ] Target at about **1.0 m**: fast pulses (`zone2`) and "Obstacle ahead."
- [ ] Target at about **0.4 m**: continuous strong buzz (`zone1`) and "Stop."
- [ ] Move the target to about **10 cm** (closer than the sensor can measure): the `zone1` buzz continues for
      about half a second, then stops.
- [ ] Move the target away: the buzzing stops.

### G5. Drop-off at a table edge

The down-looking LiDAR compares the ground distance with a learned value. For safety it **never learns a
longer distance by itself**, and it re-learns a **shorter** stable distance only after 10 seconds.

1. A helper holds the helmet level, about **1 m above a table top**, so the down beam hits the table
   about 80 cm ahead of the helmet. A "Step up ahead." warning at the start is expected: the table is closer
   than the default ground distance.
2. Hold still for **at least 12 seconds** so the shorter table distance is learned.
3. Slowly move the helmet forward so the beam spot crosses the table edge and lands on the floor.
- [ ] **Drop pattern:** two long buzzes on all three motors, and "Step down ahead." or "Drop ahead."
- [ ] Wait 3 s (cooldown), move back over the table, then slide a box about 40 cm tall under the beam:
      three short forehead pulses and "Step up ahead."

### G6. Fault by covering the camera

1. In a normally lit room, cover the camera lens completely with an opaque cap or tape.
- [ ] Within **4 seconds**: FAULT pattern (three very quick forehead buzzes), "Camera is covered or too dark.",
      and "Distance sensors still active."
- [ ] While still covered, repeat G4 at 1.0 m: the LiDAR warning still works.
- [ ] The FAULT pattern repeats every 10 seconds.
2. Uncover the lens.
- [ ] Voice says "Camera view recovered." FAULT stops.

### G7. Phone app and settings confirmations

- [ ] The app connects to `OWSH-XXXX` without a new pairing dialog (already paired in part F).
- [ ] The app shows status (uptime, temperature, faults).
- [ ] △ B2 long press: the helmet speaks the location from the phone.
- [ ] The app's log shows what the helmet said.
- [ ] Mute the helmet from the app: the helmet says "Voice info muted by phone. Warnings are still spoken."
      Unmute again.
- [ ] Set drop-off sensitivity to low in the app: "Drop-off sensitivity set to low by phone." Set it back to normal.
- [ ] Set the volume to 20 %: "Volume set to 20 percent by phone." Set it back.

### G8. Power and temperature

- [ ] With the normal power bank, no "Power is low. Charge the battery soon." message appears in 10 minutes of use.
      If it does, the power bank or cable cannot deliver 5 V 3 A. Replace it before walking.
- [ ] Optional check that the warning works: with the helmet running, power it for a minute from a weak USB supply
      (for example a 5 V 1 A charger) while pressing △ B2 a few times. After about 10 s of under-voltage you should
      hear "Power is low. Charge the battery soon." and the app status shows under-voltage. Switch back to the
      proper power bank.
- [ ] After 15 minutes of running with the lids closed, the app shows a CPU temperature below 80 °C in room
      conditions, and "Helmet is overheating." has not been spoken.

If any item fails, fix it before going outside. Common causes are in the
[wiring guide's common mistakes](02-wiring-guide.md#8-common-mistakes).

## Part H — Calibration

Calibrate **with the actual user wearing the helmet**, in their natural walking posture. Many people
walk with the head slightly lowered, and that changes where the sensors look.

### Where settings live

All thresholds are in `firmware/config/default.yaml`. The `owsh` service starts the firmware with that file
(see `/etc/systemd/system/owsh.service`). To keep personal changes safe from updates, copy it (for example
to `config/my.yaml`), change `--config` in the service file to the copy, then run
`sudo systemctl daemon-reload && sudo systemctl restart owsh`. Running `setup_pi.sh` again rewrites the
service file, so repeat this step afterwards.

### H1. Forward LiDAR aim

1. The user stands in normal posture, facing a flat wall, **1.5 m** away (measure from the forehead).
2. Expected: `zone3` slow pulses. At 1.0 m: `zone2`. At 0.5 m: `zone1`.
3. If the zones come early, late or not at all, the beam probably points up or down. At 2 m, a
   tilt of 5° moves the beam spot about 17 cm. Check `mount_pitch_deg` and the pod's seat on its saddle.
4. Zone distances are config values (spec §5.1). Change them only with good reason, and record why.

### H2. Down-looking LiDAR tilt and height

1. With the helmet on the user's head in normal posture, a helper holds a phone inclinometer against
   the down-LiDAR facet of the pod.
2. The spec value is **50° below horizontal**. If you measure a different angle, set
   `dropoff.tilt_deg` to the measured value.
3. Measure the height of the pod above the ground when worn, and set `dropoff.sensor_height_m`
   (default 1.7 m). The firmware starts from this value. Because it **never automatically learns a longer ground
   distance** (spec §5.2 safety rule), a correct starting height matters, especially for tall users.
4. Walk slowly toward a known kerb or the top of a staircase **with a sighted helper holding the user's
   arm**. The drop warning must come before the edge.

### H3. Drop-off sensitivity

- Default: no-return (for example, very dark or wet ground) is treated as a DROP. A missed drop is worse
  than a false alarm.
- If false drop alarms on dark surfaces are too frequent, the phone app can set drop-off sensitivity
  to `low`, or the config can set `dropoff.no_return_is_drop: false`. The helmet always confirms a low setting by
  voice. **Explain the trade-off to the user and their O&M instructor before changing it.**

### H4. Camera view

With the service stopped, take a picture: `rpicam-still -o view.jpg`. A person standing 3 m ahead should
be fully in the picture, and the ground should fill roughly the lower third. If not, check the pod angle.

### H5. Vibration and voice

- Each pad must be felt clearly. If not, move the pad. **Do not raise `haptics.max_duty` above 75 %.**
  The motors are 3 V parts.
- Set voice volume and language in the phone app. Voice must be clear over street noise but must not
  hide traffic sounds.
- Teach the user the patterns with [05 · User guide](05-user-guide.md) and the simulator.

### H6. Phone app, emergency number, guardians

In the app: choose the **country emergency number** (for example 112, 119 or 911), add guardian phone
numbers, and test sending an SMS to a guardian who knows it is a test.

### H7. Enrolling faces (optional)

Only enrol people who have **agreed** to it. Stop the service first (the camera is in use), then, from the
`firmware` folder:

```bash
sudo systemctl stop owsh
.venv/bin/python -m owsh.tools.enroll_face --name "Mina" --tag friend --camera 0
sudo systemctl start owsh
```

Use `--tag avoid` for a person the user wants to be warned about. Photos and face data stay on the
helmet (spec §5.4). To see who is enrolled, use `--list`. To delete a person, use `--remove "Mina"`.

## Part I — Before the first real walk

1. Run the procedures in [07 · Test plan](07-test-plan.md), at least T2, T4, T5, T8, T9, T13 and T14.
2. The first outdoor walks are done **with the white cane or guide dog as usual**, with an O&M instructor
   or a trusted sighted companion walking alongside.
3. Start in familiar, quiet places. Build up slowly.
4. Record what went well and what did not in a [field test report](../../.github/ISSUE_TEMPLATE/field_test_report.yml).

## Switching off and looking after the memory card

- **Switch off with the safe shutdown:** hold ○ B1 and □ B3 together for 5 seconds. Wait until the LED goes out,
  then unplug the power.
- Removing power without a clean shutdown can, rarely, damage the microSD card. Teach the user the safe shutdown.
- Use a good A2 card, and **keep a backup image** of the working card (for example with Raspberry Pi
  Imager or `dd`) so the helmet can be restored in minutes.
- An NVMe drive on an M.2 HAT is more robust than microSD.

Next: [05 · User guide](05-user-guide.md)

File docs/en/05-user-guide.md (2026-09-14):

# 05 · User Guide

> Part of the Open Walking Safety Helmet · Licensed CC BY 4.0 · © 2026 CLSOFTLAB, Dr. Lee Il-guk

This guide is for the person who wears the helmet. It is also for family members and
orientation and mobility (O&M) instructors.

It is written to work well with a screen reader. Each part has a heading. Important tables are also
given as plain lists.

## Contents

1. The most important thing
2. What the helmet does
3. Putting it on
4. Switching on and off
5. Vibration language
6. Buttons
7. Voice messages
8. Emergency (SOS)
9. Phone app and pairing
10. Charging and daily care
11. Rain, heat, cold and night
12. What the helmet cannot do
13. Learning with an instructor
14. Quick reference card
15. Getting help

---

## 1. The most important thing

**The helmet helps. It does not replace your white cane or your guide dog.**

- Always walk with your cane or dog, as you were trained.
- The helmet mainly warns about things your cane cannot reach: things at head height, and things
  moving toward you.
- If the helmet is silent, it does **not** always mean the way is clear.
- If you feel three very quick buzzes on your forehead, something inside is broken. Walk with your
  cane only, and ask for help to check the helmet.

## 2. What the helmet does

- Warns about things at **head height** in front of you. For example branches, signs, truck mirrors,
  open windows.
- Warns about **steps down, stairs, kerbs and platform edges** in front of you.
- Warns about **steps up** and low obstacles in front of you.
- Warns about **people, bicycles, cars and dogs moving toward you**, and says which side.
- **Reads text** in front of you when you press a button. For example signs and labels.
- **Describes what is in front of you** when you press a button.
- Tells you when a **friend** you have enrolled is nearby.
- Sends an **emergency alert** to your phone if you hold a button or fall.
- Warns you when its **power is low** or it is **overheating**.

Why a helmet? Sensors can miss things. If you do bump into something, the helmet still protects your head.

## 3. Putting it on

1. Find the **buttons**. They are on the **right side**, above your ear.
2. Put the helmet on, with the buttons on your right.
3. The helmet sits level. The front edge is about two fingers above your eyebrows.
4. Close the chin strap. You should fit one finger between the strap and your chin.
5. Turn the fit dial at the back until the helmet does not wobble when you shake your head.
6. Check that you can feel the three vibration pads: left temple, middle of forehead, right temple.
7. Put on the headset. It sits in front of your ears and **leaves your ears open**, so you can still
   hear traffic.
8. Put the power bank in a pocket or waist bag. Plug in the magnetic cable.
9. Make sure the cable runs down your back. Never around your neck.

The magnetic plug is designed to come apart if the cable is pulled hard. That protects your neck.

## 4. Switching on and off

### Switching on

1. Plug the magnetic cable into the helmet. The helmet starts by itself.
2. Wait about one minute.
3. You hear "Helmet ready." and a reminder that the helmet only assists.
4. You feel the **ready** signal: a quick sweep **left, forehead, right**.
5. Now the helmet is working.

Each morning, before you leave, check:

- You felt the ready sweep.
- Press the square button (□) once. You hear the status report, for example "All systems working."
- There is no fault signal (three very quick forehead buzzes).

### Switching off safely

1. Press the **circle (○)** and the **square (□)** buttons **at the same time**. Press them within about
   one second of each other.
2. **Hold both for 5 seconds.**
3. You hear "Shutting down." and feel the sweep **backwards: right, forehead, left**.
4. About 3 seconds later the helmet is off. Then you can unplug the magnetic cable.

Good to know:

- While you hold both buttons, the helmet will **not** start an emergency alert and will not repeat a message.
- If you let go of either button before 5 seconds, nothing happens. The helmet keeps running.
- Please use this way to switch off. Just unplugging can, rarely, damage the helmet's memory card.

## 5. Vibration language

There are three vibration points:

- **Left temple**
- **Forehead** (middle)
- **Right temple**

Three simple ideas help you remember:

- **Forehead only** means something is **in front of your face**.
- **All three together** means **the ground** in front of you changes.
- **One side** means something is **on that side**, often moving toward you.

The stronger and faster the vibration, the more urgent it is.

### 5.1 Things in front of your face (forehead)

- **Slow, gentle taps**, about two per second.
  - Meaning: something at head height, **1.2 to 2 metres** ahead.
  - No voice.
  - What to do: slow down, pay attention.
- **Fast buzzing taps**, about five per second.
  - Meaning: something at head height, **0.6 to 1.2 metres** ahead.
  - Voice: "Obstacle ahead."
  - What to do: slow down, check with your cane or hand, change direction.
- **Buzz that does not stop**, strong.
  - Meaning: something **very close**, less than 0.6 metres.
  - Voice: "Stop."
  - What to do: **stop now.** Check with your hand.
  - Note: when something is closer than about 20 centimetres, the sensor cannot measure it. The buzz
    continues for half a second and then stops. Stopping buzz does not mean it has gone.

Think of it like a car parking sensor: the closer, the faster, until it becomes continuous.

### 5.2 The ground in front of you

- **Two long, strong buzzes on all three points.**
  - Meaning: **step down, stairs down, kerb or edge** ahead.
  - Voice: "Step down ahead." or, for a bigger drop, "Drop ahead."
  - What to do: **stop. Find the edge with your cane.**
  - Note: very dark or wet ground can also cause this warning.
- **Three short taps on the forehead.**
  - Meaning: **step up** or a low obstacle ahead.
  - Voice: "Step up ahead."
  - What to do: slow down, find it with your cane.

### 5.3 Something moving toward you

- **Three strong, quick buzzes on one side** (left, right, or forehead for straight ahead).
  - Meaning: a person, bicycle, car or dog is **moving toward you from that side**.
  - The voice names what it is and the side.
  - **Urgent**, with strong buzzes: for example "Watch out, bicycle on the right!"
  - **Earlier warning**, with weaker buzzes: for example "Bicycle approaching from the right."
  - What to do: stop or move away from that side, as you judge safe.

### 5.4 People you know

- **Two soft taps on one side.**
  - Meaning: an enrolled **friend** is on that side.
  - Voice: for example "Mina is ahead on the left."
- **Four fast, sharp buzzes on one side.**
  - Meaning: a person you asked to be **warned about** is on that side.
  - Voice: for example "Caution, Mina on the left."

### 5.5 System signals

- **One tiny tap on the forehead.**
  - Meaning: "Got it". A button press was accepted.
- **Quick sweep left, forehead, right.**
  - Meaning: the helmet is **ready**.
- **Quick sweep right, forehead, left** (backwards).
  - Meaning: the helmet is **switching off**.
- **A number of even taps on the forehead.**
  - Meaning: a **number**, for example a floor number. Count the taps. Up to 10.
- **All three points pulse once every second.**
  - Meaning: the **emergency alert countdown** is running. It lasts 10 seconds.
  - What to do: press **any button** to cancel if you do not need help.
- **Three very quick buzzes on the forehead, repeating every 10 seconds.**
  - Meaning: **something important is broken** (a FAULT): the camera, a distance sensor, the vibration motors
    or the motion sensor.
  - A voice tells you what failed, for example "Front distance sensor not working."
  - What to do: **do not trust silence.** Walk with your cane only. Ask someone to check the helmet.
  - Less important parts, such as face recognition or Bluetooth, are announced once by voice, without repeating.

### 5.6 Coming later

- **Slow pulses on the left or right temple** will mean "turn left" or "turn right". This is for
  navigation in a future version. Version 1.0 does not use it yet.

### 5.7 Vibration table (same information as above)

| Pattern | Where | Feels like | Meaning |
|---|---|---|---|
| tick | Forehead | One tiny tap | Button accepted |
| zone3 | Forehead | Slow gentle taps | Head-height obstacle 1.2–2.0 m |
| zone2 | Forehead | Fast buzzing taps, and "Obstacle ahead." | Head-height obstacle 0.6–1.2 m |
| zone1 | Forehead | Continuous strong buzz, and "Stop." | Obstacle closer than 0.6 m |
| drop | All three | Two long strong buzzes | Step down, stairs, edge |
| step_up | Forehead | Three short taps | Step up, low obstacle |
| approach | Left, right or forehead | Three strong quick buzzes | Something moving toward you from that side |
| friend | One side | Two soft taps | Enrolled friend on that side |
| avoid | One side | Four fast sharp buzzes | Person to avoid on that side |
| count | Forehead | Even taps, count them | A number (up to 10) |
| SOS countdown | All three | One pulse per second, 10 s | Emergency alert will be sent. Press any button to cancel. |
| fault | Forehead | Three very quick buzzes every 10 s | Something important is broken. Do not trust silence. |
| ready | Left, forehead, right | Quick sweep | Helmet ready |
| shutdown | Right, forehead, left | Quick sweep backwards | Helmet switching off |

## 6. Buttons

There are three buttons on the **right side**, above your ear. Each has a different shape and number of dots:

- **Front: circle ○, one dot**
- **Middle: triangle △, two dots**
- **Rear: square □, three dots**

Every press you make is confirmed by one tiny tap on the forehead.

Ways to press:

- **Short press:** press and let go quickly, in less than about 1 second.
- **Long press:** hold for 1.5 seconds or more. For the square, hold 3 seconds.
- **Double press:** two quick presses.
- A press that is a little too long for short but too short for long is ignored. Just press again.

### Circle ○ (front)

- **Short press:** read text in front of you. Face the sign or label, keep still, then press.
- **Long press:** repeat the last message.

### Triangle △ (middle)

- **Short press:** describe what is in front of you. For example "2 people ahead, bicycle on the right".
- **Long press:** where am I. The helmet asks your phone for the location and says it.
- **Double press:** who is here. The helmet tells you if it sees enrolled friends.

### Square □ (rear)

- **Short press:** status report. The helmet tells you if everything is working, if the phone is connected,
  and if voice info is muted.
- **Double press:** voice mute on or off. See the note below.
- **Hold for 3 seconds:** start an **emergency alert**. The countdown starts while you are still holding.
  See section 8.

### Circle ○ and square □ together

- **Hold both for 5 seconds:** switch the helmet off safely. See section 4.

### About mute

- Mute silences less urgent speech, such as friend names and small notices.
- **Answers to your own button presses are still spoken** when muted: text reading, scene description,
  status report, where am I, and who is here.
- Warnings such as "Stop.", "Step down ahead.", power warnings and fault messages are **always spoken**.
- Vibration is never muted.

### Button table (same information as above)

| Button | Short press | Long press | Double press |
|---|---|---|---|
| ○ circle, front, 1 dot | Read text | Repeat last message | None |
| △ triangle, middle, 2 dots | Describe scene | Where am I | Who is here |
| □ square, rear, 3 dots | Status report | Hold 3 s: emergency alert | Voice mute on or off |
| ○ and □ together | Hold 5 s: safe shutdown | | |

## 7. Voice messages

The voice speaks through the open-ear headset. Urgent messages interrupt less urgent ones.

The exact wording depends on your language. These are the English messages.

### Warnings, always spoken

- "Stop."
- "Obstacle ahead."
- "Step down ahead." or "Drop ahead."
- "Step up ahead."
- Approach warnings, for example "Watch out, bicycle on the right!" or "Bicycle approaching from the right."
- A warning about a person you asked to avoid, for example "Caution, Mina on the left."

### Power and temperature, always spoken

- **"Power is low. Charge the battery soon."**
  - The power bank is weak or nearly empty, or the cable is poor.
  - Change to a charged power bank soon. The helmet may switch off without more warning.
  - Repeated at most every 5 minutes.
- **"Helmet is overheating."**
  - The computer is too hot, for example in strong sun.
  - Move into shade if you can. Warnings about moving things may come later while it is hot.
  - Repeated at most every 5 minutes.

### Faults, always spoken

- "Camera is covered or too dark."
- "Distance sensors still active." This means the head-height and step-down warnings still work.
- A part that stopped working, for example "Front distance sensor not working."
- When it works again, for example "Camera view recovered."

### Emergency, always spoken

- "Emergency alert in 10 seconds. Press any button to cancel."
- "Sending emergency alert to the phone."
- "Emergency alert sent."
- "Emergency alert cancelled."
- "Phone not connected."
- "Fall detected."

### Settings changed from the phone, always spoken

The helmet tells you when the phone makes it less safe, so it can never happen silently:

- "Voice info muted by phone. Warnings are still spoken."
- "Drop-off sensitivity set to low by phone."
- "Volume set to 20 percent by phone." (for any volume below 30 percent)
- **"New phone paired: …"** with the phone's name.

If you hear one of these and **you or your helper did not change it**, someone else may be connected. Tell the
person who looks after your helmet. See section 9.

### Answers to your button presses (spoken even when muted)

- Scene descriptions, for example "2 people ahead, bicycle on the right."
- Text that was read. Dangerous signs start with "Warning sign:".
- Status report, for example "All systems working." or "Voice info is muted."
- Where am I, for example "You are near …".
- Who is here, for example "No one I know."
- "Text reading is not installed.", if that feature has not been set up.

### Other messages (not spoken when muted)

- Friend names, for example "Mina is ahead on the left."

If you missed a message, long-press the circle ○.

## 8. Emergency (SOS)

### Starting an alert

There are two ways:

- **Hold the square □ button for 3 seconds.**
- **A fall.** If the helmet detects that you fell and are lying still, it starts by itself and says "Fall detected."

### The countdown

1. All three vibration points pulse once every second.
2. The voice says: "Emergency alert in 10 seconds. Press any button to cancel."
3. **To cancel:** press any button. The voice says "Emergency alert cancelled."
4. If you do not cancel, after 10 seconds the helmet sends the alert to your phone.

### "Sending" and "sent" mean different things

- **"Sending emergency alert to the phone."** The helmet is trying. It repeats the alert every 5 seconds
  until the phone answers. **Help is not on its way yet.**
- **"Emergency alert sent."** You hear this **only after the phone has confirmed** that it received the alert.
  The emergency screen is now open on the phone.

### On the phone

- The phone sounds a loud alarm and vibrates.
- It shows your location.
- It shows two big buttons: **call the emergency number** and **send an SMS to your guardians**
  with a map link.
- **Someone must press the button on the phone.** That can be you, or a person nearby.
  The phone app cannot call automatically in this version.

### If the phone is not connected

- The voice says "Phone not connected." every 10 seconds.
- The vibration continues for 60 seconds, and the status light blinks fast, so people nearby notice.
- Any button press stops it.
- Call for help out loud, and use your phone directly if you can.

### Please practise

Practise starting and cancelling an alert at home with your family or instructor. Tell your guardians
before you test sending a real SMS.

## 9. Phone app and pairing

The phone app is a web app that connects to the helmet by Bluetooth. It works with screen readers.

What it does:

- Connects to your helmet. The helmet's name starts with `OWSH-`.
- Shares your location with the helmet, for "where am I".
- Shows the emergency screen (section 8).
- Settings: language, voice volume, mute, and drop-off sensitivity.
- Settings: your country's emergency number and your guardians' phone numbers.
- A log of everything the helmet said, so you can read it again with your screen reader.

Phones:

- **Android:** use Chrome. The person who set up your helmet can add the app to your home screen.
- **iPhone:** Safari cannot use Bluetooth from a web page. Use the free **Bluefy** browser app. A native app is planned.

### Pairing your phone

The helmet only listens to **your** paired phone. The connection is encrypted. Other phones nearby cannot
control it.

1. Switch the helmet on.
2. If a phone was paired before, pair **within 2 minutes** of switching on. The first time, there is no time limit.
3. In the app, tap **Connect** and choose the helmet named `OWSH-` followed by four characters.
4. The phone asks **"Pair with OWSH-…?"**. There is no PIN. Choose **Pair**. Your screen reader reads the question.
5. The helmet says **"New phone paired: …"** with your phone's name.
6. Next time, the phone connects by itself.

To use a new phone, switch the helmet off and on, then pair the new phone within 2 minutes.

**If you ever hear "New phone paired" and you did not pair a phone,** tell the person who looks after your
helmet. They can remove the pairing.

Keep the phone charged and Bluetooth on. The helmet's warnings work **without** the phone. The phone
is needed for location and emergency alerts.

## 10. Charging and daily care

### Charging

- The helmet has no battery inside. It runs from the **power bank** in your pocket.
- **Charge the power bank every night.**
- Roughly, a 10 000 mAh power bank lasts about 3.5 hours. A 20 000 mAh power bank lasts about 7 hours.
  Cold weather and old batteries give less.
- The helmet cannot read how full the power bank is. "Power is low. Charge the battery soon." comes only when
  the power is already weak. **Some power banks switch off with no warning at all.** Then the helmet stops
  silently. For long days, carry a second charged power bank.

### Daily care

- Wipe the **camera window** and the two **sensor windows** at the front with a soft, dry cloth.
  Dirt, rain drops and fingerprints make the helmet less reliable.
- Do not put stickers, caps or hair clips over the front windows.
- Check that the cable and magnetic plug are not damaged.
- Do not leave the helmet in a hot car or in direct sun on a bench.

### Replace the helmet if

- It has had a hard hit, a fall onto its shell, or a crash. Even if it looks fine, the foam inside may be
  crushed. The modules can be moved to a new helmet.
- The shell is cracked, or the foam is dented.
- The helmet maker's recommended lifetime has passed.

## 11. Rain, heat, cold and night

### Rain

- The helmet is **not waterproof**. It is made to survive light rain.
- Rain drops on the front windows can cause false warnings, or the fault "Camera is covered or too dark."
- In **heavy rain**, fog or snow, the helmet becomes unreliable. Rely on your cane.
- After rain, dry the helmet at room temperature. Do not use a hair dryer or heater.
- Never put the helmet under a tap or in water.

### Heat

- In strong sun, the helmet's computer gets warm and may slow down. Warnings about moving things may come later.
- If you hear "Helmet is overheating.", move into shade if you can.
- Bright sunlight also shortens how far the distance sensors can see.

### Cold

- Power banks give less energy in the cold. Keep the power bank in an inside pocket.

### Night and darkness

- The distance sensors (head-height and step-down warnings) **work in the dark**.
- The camera **does not** work well in the dark. Warnings about approaching people and vehicles, text
  reading and face recognition may not work.
- In a very dark place you may get the fault "Camera is covered or too dark." The voice then says
  "Distance sensors still active."

## 12. What the helmet cannot do

Please read this with your family and your instructor.

- It **cannot replace** your cane, guide dog or O&M skills.
- The head-height sensor looks in a **narrow line straight ahead**. Things to the side, and very thin
  things like wires and thin branches, can be missed. Turning your head slowly helps.
- Things **closer than about 20 cm** cannot be measured. The warning stops after half a second.
- **Glass** doors and windows can be missed.
- It does **not** see low obstacles well, except as "Step up". Your cane does that job.
- It does **not** see things coming **from behind**.
- It can give **false warnings**, especially on dark or wet ground, in rain, or near shiny surfaces.
- It can **misread** text, and it can **mistake** one face for another.
- It does **not** know traffic lights or whether it is safe to cross a road.
- It does **not** give turn-by-turn navigation in this version.
- It cannot tell how full the power bank is. It may stop with no warning when the power runs out.

## 13. Learning with an instructor

We strongly recommend learning to use the helmet with an O&M instructor.

Suggested steps:

1. **At home, sitting down.** Learn each vibration pattern. A helper can use the computer simulator to
   play them.
2. **At home, walking.** Practise with a helper holding objects at head height.
3. **In a quiet, familiar place outside,** with your cane and a sighted helper.
4. **In busier places,** step by step, only when you feel ready.
5. Practise the emergency alert and cancelling it.
6. Practise the safe shutdown with both buttons.

Instructors: please share what you learn in a
[field test report](../../.github/ISSUE_TEMPLATE/field_test_report.yml).
It helps everyone.

## 14. Quick reference card

You can print this part, or copy it into a note on your phone.

- Buttons on the **right**. Front ○ circle one dot, middle △ triangle two dots, rear □ square three dots.
- ○ short: read text. ○ long: repeat.
- △ short: describe. △ long: where am I. △ double: who is here.
- □ short: status. □ double: mute. □ hold 3 seconds: emergency.
- ○ and □ together, hold 5 seconds: switch off.
- Forehead slow taps: something ahead at head height, 1.2 to 2 m.
- Forehead fast taps: 0.6 to 1.2 m.
- Forehead continuous: **stop**.
- All three, two long buzzes: **step down ahead. Stop and check.**
- Forehead three short taps: step up.
- One side, three strong buzzes: something moving toward you from that side.
- One side, two soft taps: a friend.
- All three, once per second: emergency countdown. Any button cancels.
- "Sending emergency alert": still trying. "Emergency alert sent": the phone has it.
- Forehead three very quick buzzes every 10 seconds: **broken. Do not trust silence.**
- "Power is low": change the power bank soon.
- Sweep left, forehead, right: ready. Sweep right, forehead, left: switching off.
- "New phone paired" when you did not pair: tell your helper.
- **Always use your cane or guide dog.**

## 15. Getting help

- The person or group who built your helmet is your first contact.
- For problems with the design, anyone can report on the project's GitHub page. Issues are written in
  English, but Korean is welcome. See [CONTRIBUTING.md](../../CONTRIBUTING.md).
- Safety information: [06 · Safety](06-safety.md).

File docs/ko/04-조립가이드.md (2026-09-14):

# 04 · 조립 가이드

> 오픈 보행 안전 헬멧 프로젝트 문서 · CC BY 4.0 라이선스 · © 2026 씨엘소프트랩(CLSOFTLAB), 이일국 박사

이 가이드는 부품 상자에서 시작해 점검까지 마친 헬멧을 완성하는 과정을 안내합니다. 3D 프린팅 시간을 빼고 하루나 이틀 정도 잡으십시오.

시작하기 전에 [06 · 안전수칙](06-안전수칙.md)을 먼저 읽으십시오. 가장 중요한 규칙은 두 가지입니다.

1. **헬멧 외피(셸)나 충격흡수 스티로폼(EPS) 라이너에 절대 구멍을 뚫거나, 자르거나, 접착제를 바르거나, 녹이지 마십시오.**
   모든 부품은 통풍구에 통과시킨 스트랩과 떼어낼 수 있는 패드로 붙입니다.
2. **헬멧은 보조 도구입니다. 흰지팡이, 안내견, 보행 훈련(O&M)을 절대 대신하지 않습니다.**

## 차례

- [A. 준비](#a-준비)
- [B. 소프트웨어 설치](#b-소프트웨어-설치)
- [C. 책상 위 배선과 첫 점검](#c-책상-위-배선과-첫-점검)
- [D. 모듈 만들기](#d-모듈-만들기)
- [E. 구멍 뚫지 않고 헬멧에 장착하기](#e-구멍-뚫지-않고-헬멧에-장착하기)
- [F. 휴대폰 페어링(등록)](#f-휴대폰-페어링등록)
- [G. 첫 부팅 점검표](#g-첫-부팅-점검표)
- [H. 보정](#h-보정)
- [I. 첫 실제 보행 전에](#i-첫-실제-보행-전에)
- [전원 끄기와 메모리 카드 관리](#전원-끄기와-메모리-카드-관리)

---

## A. 준비

- [ ] [01 · 부품목록](01-부품목록.md)에 있는 모든 부품. W3 분배선(splitter)과 W4 USB 연장 케이블도 포함합니다.
- [ ] [03 · 3D 프린팅 가이드](03-3D프린팅가이드.md)에 따라 출력한 모든 부품. 다듬고 맞춰 보기까지 끝낸 상태여야 하며,
      곡면 부품은 **사용할 헬멧**에서 잰 반지름에 맞춰 렌더링해야 합니다.
- [ ] microSD 카드 리더가 있는 컴퓨터와 [Raspberry Pi Imager](https://www.raspberrypi.com/software/).
- [ ] 설정용 Wi-Fi. 소프트웨어 설치에만 필요하며, 그 뒤에는 헬멧이 인터넷 없이 작동합니다.
- [ ] 휴대폰 앱을 쓸 Chrome이 설치된 안드로이드 휴대폰(또는 Bluefy 브라우저를 설치한 아이폰).
- [ ] 주방용 저울. **지금 빈 헬멧의 무게를 재서** 적어 두십시오.
- [ ] 헬멧 외피를 닦을 순한 비누, 물, 천.

## B. 소프트웨어 설치

### B1. Raspberry Pi OS Bookworm 64비트 설치

1. microSD 카드를 컴퓨터에 넣고 Raspberry Pi Imager를 엽니다.
2. **장치(Device):** Raspberry Pi 5.
3. **운영체제(Operating system):** **Debian 12 "Bookworm"** 기반의 *Raspberry Pi OS (64-bit)*.
   Imager의 기본값이 더 새로운 릴리스라면 *Raspberry Pi OS (other)*를 열고 Bookworm
   64-bit (Legacy) 이미지를 고릅니다. 펌웨어 v1.0은 Bookworm 기준으로 만들고 시험했습니다.
4. **저장소(Storage):** 사용할 microSD 카드.
5. **설정 편집(Edit settings)** (OS 사용자 지정):
   - 호스트 이름. 예: `owsh-01`.
   - 사용자 이름과 강력한 비밀번호. 헬멧 주인을 위해 적어 둡니다.
   - Wi-Fi 네트워크와 국가.
   - 시간대와 키보드 배열.
   - 서비스: **SSH** 켜기(비밀번호 또는 키).
6. 카드에 기록한 다음 Pi에 꽂습니다.

### B2. 첫 시작과 업데이트

1. 설정하는 동안에는 Pi를 일반 USB-C 전원 어댑터(5 V 3 A 또는 공식 27 W 어댑터)에 연결합니다.
2. 1–2분 기다린 뒤 컴퓨터에서 접속합니다: `ssh <user>@owsh-01.local`.
3. 시스템을 업데이트합니다.
   ```bash
   sudo apt update && sudo apt full-upgrade -y
   sudo reboot
   ```

### B3. 펌웨어 설치

1. 프로젝트를 받고 `firmware` 폴더로 이동합니다.
   ```bash
   sudo apt install -y git
   git clone <repository-url> owsh
   cd owsh/firmware
   ```
   저장소 URL은 프로젝트 GitHub 페이지에 나온 주소를 사용합니다.
2. 설치 스크립트를 **일반 사용자로** 실행합니다(`sudo`를 붙이지 마십시오. 필요할 때 비밀번호를 묻습니다).
   ```bash
   bash scripts/setup_pi.sh          # add --ocr to also install text reading
   ```
   (`--ocr`을 붙이면 글자 읽기 기능도 함께 설치합니다.)
   이 스크립트가 하는 일은 다음과 같습니다.
   - 시스템 패키지를 설치합니다(카메라, GPIO, `espeak-ng`, `i2c-tools`, `bluez`, `bluez-tools`).
   - `config.txt`에서 I2C를 400 kHz로 켜고 카메라를 켭니다.
   - 가상환경 `firmware/.venv`를 만들고 펌웨어를 설치합니다.
   - AI 모델을 내려받고 자체 시험을 실행합니다.
   - 서비스 두 개를 설치하고 켭니다. **`owsh`**(헬멧 펌웨어)와 **`owsh-bt-agent`**(블루투스
     페어링 에이전트)입니다.
   - 헬멧의 안전하게 끄기 동작으로 Pi 전원을 끌 수 있도록 허용합니다.
3. 재부팅합니다: `sudo reboot`.
4. 서비스 상태를 확인합니다.
   ```bash
   systemctl status owsh owsh-bt-agent
   journalctl -u owsh -f
   ```
   센서를 연결하지 않은 상태에서는 FAULT 메시지가 보입니다. 이것은 예상된 정상 동작입니다(설계서 P4).
   센서가 빠졌는데 "이상 없음"처럼 보여서는 절대 안 되기 때문입니다.

이 가이드에서 펌웨어 도구는 `firmware` 폴더에서 가상환경의 Python으로 실행합니다:
`.venv/bin/python -m owsh.tools.<tool>`.

**글자 읽기(OCR)**는 선택 설치 항목입니다(설계서 §5.5). `--ocr` 없이 설치했다면 원(○) 버튼을 눌렀을 때
"문자 읽기 기능이 설치되어 있지 않습니다."라고 말합니다. 나중에 추가하려면 `.venv/bin/pip install -e ".[ocr]"`를 실행한 뒤
`sudo systemctl restart owsh`를 실행합니다.

**먼저 시뮬레이터로 익혀 보기(선택).** 웹캠이 있는 PC라면 어디서든
`python -m owsh --sim`을 실행해, 하드웨어가 준비되기 전에 진동 패턴과 버튼을 익힐 수 있습니다
([`firmware/README.md`](../../firmware/README.md) 참고).

## C. 책상 위 배선과 첫 점검

1. 전원을 끕니다. [02 · 배선 가이드](02-배선가이드.md)에 따라 모든 부품을 책상 위에서 배선합니다.
2. 아래를 보는 TF-Luna의 주소를 0x11로 바꿉니다([배선 가이드](02-배선가이드.md) 6절 "TF-Luna: I2C 모드와 주소 변경").
3. [배선 가이드](02-배선가이드.md) 7절 "점검"의 항목을 모두 통과해야 합니다.
   `i2cdetect -y 1`에 `10`, `11`, `68`이 보이고, 카메라가 목록에 나오고, 버튼 값이 `hi`/`lo`로 읽히고,
   부팅할 때 모터가 왼쪽 → 가운데 → 오른쪽 순서로 떨립니다.

**책상 위 조립이 모든 점검을 통과할 때까지 다음 단계로 넘어가지 마십시오.** 고장은 헬멧 위의 닫힌 케이스 안보다
책상 위에서 훨씬 찾기 쉽습니다.

## D. 모듈 만들기

각 단계를 시작하기 전에 전원을 끕니다. 나사 규격은 [`hardware/README.md`](../../hardware/README.md)에 정리되어 있습니다.
셀프태핑 구멍은 나사를 한 번 끝까지 박았다가 다시 빼낸 다음 조립합니다.

### D1. 전방 센서 포드 (`front_pod_base`, `front_pod_cover`)

1. **Camera Module 3 Wide**를 카메라 칸에 M2 × 5 나사 4개로 고정합니다. 렌즈는 창을 통해
   10° 아래를 봅니다. 너무 세게 조이지 마십시오. 기판이 깨질 수 있습니다.
2. 무엇이든 닫기 전에 카메라 케이블의 15핀 쪽을 먼저 연결합니다.
3. **S1(전방 TF-Luna)**을 앞쪽 칸에 렌즈가 앞을 향하도록 넣습니다(M2 × 5 나사 2개).
4. **S2(아래쪽 TF-Luna, 0x11 라벨)**를 50° 경사면 칸에 렌즈가 앞쪽 아래를 향하도록 넣습니다(M2 × 5 나사 2개).
5. **렌즈를 가리지 마십시오.** 앞에서 확인합니다. TF-Luna 두 개의 구멍과 카메라 렌즈가 완전히 트여 있어야 하고,
   빗물 차양(rain visor)이 시야 안으로 내려오지 않아야 합니다.
6. 카메라 리본 케이블과 TF-Luna 케이블 2개를 뒤쪽 벽의 케이블 출구로 빼냅니다.
7. `front_pod_cover`를 닫습니다(M2 × 8 나사 4개).
8. 극세사 천으로 렌즈를 닦습니다.

### D2. 메인 케이스 (`main_case_base`, `main_case_lid`)

메인 케이스에는 **Active Cooler를 단 Pi 5, MPU-6050, 상태 LED**만 들어갑니다.

1. Pi 5에 **Active Cooler**를 장착합니다(제품 상자에 든 설명서를 따릅니다).
2. M2.5 × 6 나사 4개로 Pi를 스탠드오프 위에 고정합니다. USB-C 전원 단자, USB-A 포트, 쿨러 배기구가
   각각의 구멍과 맞아야 합니다.
3. **MPU-6050**을 홈에 밀어 넣습니다. 단단히 고정합니다. 낙상 감지는 전체 가속도를 쓰므로 방향은 상관없습니다.
   하지만 헐거운 IMU는 덜걱거리면서 충격처럼 보일 수 있습니다.
4. 3 mm 상태 LED를 뚜껑 안쪽에서 눌러 끼웁니다.
5. 카메라 리본 케이블의 22핀 쪽을 **CAM/DISP 0**에 연결합니다.
6. 책상 위 조립 때와 똑같이 듀폰 선을 연결합니다. 분배선은 감싼 상태로 둡니다. ULN2003으로 가는 선
   (IN1–IN3, 5 V, GND)은 케이스 밖으로 나가 보조 포드로 향합니다.
7. **W4 USB-A 연장 케이블**을 검은색 USB 2.0 포트에 꽂습니다. 소켓 쪽 끝은 뒤쪽 구멍으로 빼냅니다.
8. 뚜껑을 닫습니다(M2.5 × 8 나사 4개). 끼인 선이 없어야 합니다. 쿨러 팬이 자유롭게 돌아야 합니다.
   팬과 뚜껑 사이 틈은 약 1.2 mm뿐입니다.

### D3. 보조 포드 (`aux_pod_base`, `aux_pod_lid`)

뒤통수 쪽에 다는 보조 포드(aux pod)에는 **ULN2003 드라이버**와 **USB 오디오 어댑터**가 들어갑니다.

1. ULN2003 기판을 거치대(cradle)에 넣습니다. 메인 케이스에서 온 선 중 IN1/IN2/IN3(GPIO17/27/22), "+"(5 V),
   "−"(GND)를 연결합니다.
2. 배선 가이드대로 모터 선 3개를 ULN2003에 연결합니다. 모터 선은 **아래쪽 홈**으로 빠져나가
   헬멧 안쪽 쿠션 패드 쪽으로 향합니다.
3. USB 오디오 어댑터를 W4 연장 케이블에 꽂고 레일에 밀어 넣습니다. 헤드셋 단자가 단자 구멍을
   향해야 합니다.
4. 뚜껑을 닫습니다(M2.5 × 8 나사 4개).

### D4. 버튼 모듈 (`button_module`, `button_caps`)

1. 12 mm 스위치 3개를 끼웁니다.
2. **앞에서 뒤로** 이 순서대로 캡을 눌러 끼웁니다: **원(○), 점 1개(B1)**, **세모(△), 점 2개(B2)**,
   **네모(□), 점 3개(B3)**.
3. 선을 연결합니다: B1 → GPIO5(29번 핀), B2 → GPIO6(31번 핀), B3 → GPIO26(37번 핀). 각각 GND도 연결합니다.
   버튼 모듈 기판을 쓴다면 **3.3 V만** 연결합니다.
4. 눈을 감고 손으로 만져 다시 확인합니다. 원은 앞, 세모는 가운데, 네모는 뒤입니다.

### D5. 진동 패드 (`haptic_pad` × 3)

1. TPU 패드마다 코인 모터를 옆에서 하나씩 밀어 넣습니다. 얇은 피부 접촉막이 머리 쪽을 향합니다.
2. 벨크로(찍찍이)의 **갈고리(hook)** 쪽 조각을 홈에 붙입니다.
3. 패드에 라벨을 붙입니다: **L**(M1), **C**(M2), **R**(M3).

## E. 구멍 뚫지 않고 헬멧에 장착하기

> **모든 단계에 적용되는 규칙:**
> - 헬멧 외피(셸)나 충격흡수 스티로폼(EPS) 라이너에 구멍 뚫기, 자르기, 접착제 바르기, 가열하기, 녹이기를 하지 않습니다.
> - 쓸 수 있는 방법은 기존 통풍구에 통과시킨 스트랩, 외피 **바깥** 면에 붙이는 떼어낼 수 있는 3M 듀얼락 패드,
>   그리고 **헬멧 안쪽 쿠션 패드**에 붙이는 벨크로(찍찍이)뿐입니다. 스트랩을 나사, 케이블 타이, 접착제로 대신하지 마십시오.
> - 외피에서 튀어나오는 높이: 전방 센서 포드 **35 mm** 이하, 메인 케이스 **40 mm** 이하, 나머지 모든 모듈 **30 mm** 이하.
>   바깥 모서리는 모두 둥글게 만듭니다. 모듈 아래에 받침 기둥을 세우거나 5 mm보다 큰 틈을 두지 않습니다.

### 모듈별 위치

| 모듈 | 위치 |
|---|---|
| 전방 센서 포드 | 앞 윗부분, 이마 위 가운데 |
| 메인 케이스 | 머리 꼭대기, 정수리 뒤쪽, 긴 변이 앞뒤 방향 |
| 보조 포드 | 뒤통수, 메인 케이스 아래 |
| 버튼 모듈 | 오른쪽 옆면, 귀 위, 아래 테두리 가까이 |
| 진동 패드 | 안쪽 헬멧 쿠션 패드 위: 왼쪽 관자놀이, 이마 가운데, 오른쪽 관자놀이 |

### E1. 외피 청소

장착할 부분을 순한 비누와 물로 씻고 완전히 말립니다. 아세톤이나 독한 알코올 같은 **용제는 쓰지 마십시오.**
많은 헬멧 제조사가 용제가 외피를 약하게 만들 수 있다고 경고합니다. 3M 듀얼락은
15 °C 이상에서 가장 잘 붙고, 약 24–72시간이 지나면 최대 접착력에 이릅니다.

### E2. 새들(받침 패드)

큰 모듈 세 개는 `saddle_pad` 판에서 나온 3 mm TPU 새들(받침 패드)에 각각 올립니다(포드, 케이스, 보조 포드).

1. 새들마다 **양면에** 3M 듀얼락을 붙입니다(또는 벨크로).
2. 새들은 외피 위에 **올려놓기만** 하며, 외피 모양에 맞춰 휘어집니다. 외피에 절대 접착제로 붙이지 마십시오.

### E3. 전방 센서 포드

1. 포드를 새들 위에 눌러 붙입니다.
2. 이마 위, 좌우 가운데에 맞춰 외피 위에 올립니다. 옆에서 봅니다. 헬멧을 평소 자세로
   머리에 썼을 때 전방 LiDAR가 대략 수평이어야 합니다.
3. **20 mm 스트랩 2개**를 끼웁니다. 스트랩 탭 구멍으로 내려 넣고, 헬멧 통풍구를 지나 다시 위로 올라오게 합니다.
   **헐겁지 않게, 하지만 너무 조이지 않게** 채웁니다.
4. 헬멧 안쪽에서 스트랩은 라이너에 **평평하게** 붙어 있어야 하고, 머리 쪽에 꼬임이나 버클이 없어야 합니다.
   헬멧 안쪽 쿠션 패드가 스트랩을 덮습니다.
5. 포드 양 끝에서 새들과 외피 사이의 틈을 확인합니다. 틈이 몇 mm보다 크다면 포드가 다른 반지름에 맞춰
   렌더링된 것입니다. 다시 재고 다시 출력하십시오.

### E4. 메인 케이스

방법은 같습니다. 새들 + 3M 듀얼락 + **통풍구에 통과시킨 스트랩 2개**를 씁니다. 위치는 머리 꼭대기, 정수리 뒤쪽이며
긴 변이 앞뒤 방향을 향합니다. USB-C 구멍과 쿨러 배기구가 스트랩이나 외피에 막히면 안 됩니다.

### E5. 보조 포드

1. 새들 + 3M 듀얼락 + 뒤통수 쪽 통풍구에 통과시킨 스트랩으로, 메인 케이스 아래에 붙입니다.
2. **W4 USB 연장 케이블**과 ULN2003 선을 메인 케이스 뒤쪽 구멍에서 보조 포드까지 짧고 깔끔한 고리 모양으로
   보냅니다. `cable_clip`으로 고정합니다. 손이나 나뭇가지에 걸릴 수 있는 곳에 늘어져 있으면 안 됩니다.
3. 헤드셋 케이블은 보조 포드의 단자 구멍에서 나와 헬멧 옆면을 돌아 헤드셋으로 갑니다.
   얼굴 앞을 가로지르지 않게 합니다.

### E6. 버튼 모듈

1. 짧은 스트랩으로 옆 통풍구에 `strap_anchor`를 고정합니다.
2. 버튼 모듈을 3M 듀얼락과 비스듬한 스트랩 탭으로 붙입니다.
3. 사용자와 함께 확인합니다. 사용자가 오른손으로 더듬지 않고 바로 앞쪽의 원(○)을 찾을 수 있어야 합니다.
4. 모듈이 귀를 누르거나 안경·모자에 걸리면 안 됩니다.

### E7. 진동 패드

1. 헬멧의 떼어낼 수 있는 쿠션 패드에 벨크로의 **고리(loop)** 쪽을 붙입니다. 위치는 **왼쪽 관자놀이**,
   **이마 가운데**, **오른쪽 관자놀이**입니다. 대부분의 쿠션 패드는 원래 갈고리 테이프가 달라붙는 고리형 원단입니다.
2. 패드를 눌러 붙입니다. 충격흡수 스티로폼 라이너에는 절대 접착제로 붙이지 마십시오.
3. 사용자가 헬멧을 써 보게 합니다. 패드 하나하나가 따로, 또렷하게 느껴질 때까지 위치를 조정합니다.
   머리카락, 스카프, 모자는 진동을 약하게 만듭니다. 세기를 올리기보다 패드 위치를 옮기십시오.

### E8. 케이블 정리

1. 카메라 리본 케이블을 `fpc_cover` 안에 넣어 전방 센서 포드에서 메인 케이스까지, 외피 중심선을 따라
   스트랩 아래로 지나가게 합니다. `cable_clip`으로 고정합니다.
2. TF-Luna와 버튼의 듀폰 선도 같은 길을 따라 묶어 보냅니다. I2C 선은 각각 접지선과 꼬아 줍니다.
3. 모터 선은 보조 포드의 아래쪽 홈에서 나와 통풍구를 지나 안쪽으로 들어갑니다. 라이너 가장자리를 따라
   쿠션 패드 아래로 지나가게 해서 피부에 닿지 않게 합니다.
4. 모듈마다 여유 선을 작은 고리 모양으로 조금 남겨 둡니다. 케이블이 당겨져도 커넥터가 빠지면 안 됩니다.
5. 얼굴 앞에 늘어지거나, 귀를 가로지르거나, 턱끈 아래로 지나가는 선이 없어야 합니다.

### E9. 분리형(당기면 빠지는) 전원 케이블

보조배터리는 주머니나 허리 가방에 넣습니다. 케이블이 목에 걸릴 가능성은 절대 없어야 합니다.

1. **자석식 분리형 어댑터**를 Pi의 USB-C 단자에 꽂습니다(또는 케이블이 헬멧을 빠져나오는
   지점에 둡니다).
2. 1.5 m 케이블을 헬멧 뒤쪽에서 등을 따라 주머니나 허리 가방까지 내립니다.
3. **당김 시험:** 헬멧을 책상에 놓고 케이블을 세게 확 잡아당깁니다. 헬멧이 움직이기 전에
   자석 연결부가 먼저 떨어져야 합니다. 헬멧이 대신 끌려온다면 어댑터가 너무 세게 붙어 있는 것입니다. 교체하십시오.
4. 케이블을 목에 감거나, 조일 수 있는 방식으로 옷 사이에 통과시키지 마십시오.

### E10. 최종 기계 점검

- [ ] **외피에서의 높이**(가장 높은 지점을 캘리퍼스로 잽니다): 전방 센서 포드 35 mm 이하, 메인 케이스 40 mm 이하,
      보조 포드, 버튼 모듈, 나머지 모두 30 mm 이하.
- [ ] 어떤 모듈의 새들과 외피 사이에도 **5 mm보다 큰 틈이 없습니다**.
- [ ] **무게:** 헬멧 무게를 다시 잽니다. 늘어난 무게(보조배터리와 빗물받이 제외)가 **380 g 이하**입니다
      (예상값 약 330 g).
- [ ] **균형:** 사용자가 고개를 끄덕여도 헬멧이 앞뒤로 기울지 않습니다.
- [ ] **착용감:** 헬멧이 여전히 수평으로 앉고, 턱끈과 뒤쪽 조절 다이얼이 정상적으로 조절됩니다.
- [ ] **외피나 라이너에 구멍, 절단, 접착제가 없습니다.** 한 번 더 확인합니다.
- [ ] **모서리:** 모든 모듈을 손으로 쓸어 봅니다. 날카로운 모서리, 뾰족한 곳, 풀린 선 끝이 없습니다.
- [ ] **통풍:** 통풍구가 적어도 몇 개는 열려 있습니다.
- [ ] 헬멧 안쪽의 **인증 라벨**을 여전히 읽을 수 있습니다.

## F. 휴대폰 페어링(등록)

헬멧은 **페어링(등록)된 휴대폰**에서 온 명령만, 암호화된 연결로 받습니다(설계서 §8.3).
그렇지 않으면 근처에 있는 누구나 음성 안내를 끄거나 낙차 감지 민감도를 낮출 수 있기 때문입니다.

1. 안드로이드에서는 Chrome, 아이폰에서는 Bluefy 브라우저로 휴대폰 앱을 HTTPS 주소로 엽니다
   ([`app/README.md`](../../app/README.md) 참고).
2. 헬멧을 켭니다. **아직 등록된 휴대폰이 없으면** 페어링은 언제나 열려 있습니다. 휴대폰이 한 번 등록되면
   페어링은 **켤 때마다 처음 2분 동안만** 열립니다.
3. 앱에서 **헬멧 연결** 버튼을 누르고 `OWSH-XXXX`를 고릅니다.
4. 앱이 처음 명령을 보낼 때, 휴대폰이 평소의 시스템 대화상자를 띄웁니다. 예를 들어
   **"OWSH-XXXX와(과) 페어링하시겠습니까?"**와 같이 묻습니다(정확한 문구는 휴대폰 기종과 언어에 따라 다릅니다).
   헬멧에는 화면이나 키패드가 없으므로 PIN은 없습니다. **페어링**을 누릅니다. 화면낭독기가 이 대화상자를 소리 내어 읽어 줍니다.
5. 헬멧이 **"새 휴대폰이 등록되었습니다: <휴대폰 이름>."**이라고 말합니다. 그다음부터는 자동으로 연결됩니다.
6. **휴대폰을 추가하거나 바꾸려면** 헬멧을 다시 켜고 2분 안에 페어링합니다.
7. **등록을 모두 지우려면** Pi에서 `bluetoothctl devices Paired`를 실행한 다음, 기기마다
   `bluetoothctl remove <address>`를 실행합니다.

사용자에게 알려 주십시오. 휴대폰을 등록하지 않았는데 헬멧이 "새 휴대폰이 등록되었습니다"라고 말한다면, 다른 사람이
등록한 것입니다. 등록을 지우고 헬멧을 다시 켜십시오.

## G. 첫 부팅 점검표

실내의 안전한 방에서, 앞을 볼 수 있는 도우미와 함께 합니다. 노트북으로 로그를 지켜봅니다:
`journalctl -u owsh -f`. 항목마다 체크합니다. 아래 음성 안내는 한국어 문구 파일
(`firmware/owsh/i18n/ko.json`)에서 인용했습니다. 실제 음성 문구는 펌웨어 한국어 파일(ko.json)을 따릅니다.

### G1. 시작

- [ ] 보조배터리를 연결합니다. 상태 LED가 켜집니다.
- [ ] 1분쯤 안에 헤드셋에서 "헬멧 준비 완료."와 "이 헬멧은 보조 장치입니다. 흰지팡이나 안내견과 함께
      사용하세요."가 나옵니다.
- [ ] **준비 패턴:** **왼쪽 → 이마 → 오른쪽**으로 빠르게 훑고 지나갑니다(각 100 ms).
- [ ] 이어서 고장(FAULT) 패턴(이마에 아주 빠른 진동 세 번)이 나오지 않습니다. 나온다면 로그를 확인합니다.

### G2. 버튼 (누름이 인식될 때마다 이마에 짧은 `tick`)

- [ ] 원(○) B1 짧게(0.8초 미만): tick, 이어서 글자 읽기(또는 "문자 읽기 기능이 설치되어 있지 않습니다.").
- [ ] 원(○) B1 길게(1.5초 이상): tick, 마지막 안내를 다시 들려줍니다.
- [ ] 약 0.8초에서 1.5초 사이로 누르면 무시됩니다.
- [ ] 세모(△) B2 짧게: tick, 장면 설명.
- [ ] 세모(△) B2 길게: tick, "여기가 어디인지" 안내(휴대폰 앱이 연결되어 있어야 합니다).
- [ ] 세모(△) B2 두 번: tick, 누가 있는지(얼굴) 안내.
- [ ] 네모(□) B3 짧게: tick, 상태 안내.
- [ ] 네모(□) B3 두 번: tick, "음성 안내를 끕니다. 위험 경고는 계속 말합니다." 이어서 세모(△) B2를 짧게 누릅니다.
      장면 설명은 사용자가 직접 누른 버튼에 대한 대답이므로 **여전히 말합니다**. 네모(□)를 다시 두 번 눌러 음성 안내를 켭니다.
- [ ] 네모(□) B3 3초 누르고 있기: 아직 누르고 있는 동안 긴급 신고(SOS) 카운트다운이 시작됩니다(모터 3개가 1초에 한 번씩
      함께 떨리고, 음성으로 경고합니다). **아무 버튼이나 누르면 취소됩니다.** 취소되는지 확인합니다. 전체 SOS 시험은 나중에 합니다
      ([07 · 시험계획](07-시험계획.md) T9).

### G3. 안전하게 끄기

- [ ] 원(○) B1과 네모(□) B3를 **함께**(서로 1초쯤 안에) 누르고, 둘 다 **5초** 동안 누르고 있습니다.
- [ ] 헬멧이 "전원을 끕니다."라고 말하고, 준비 패턴이 거꾸로(**오른쪽 → 이마 → 왼쪽**) 나오고,
      약 3초 뒤 Pi 전원이 꺼집니다. 상태 LED가 꺼집니다.
- [ ] SOS 카운트다운이 시작되지 않았고, 마지막 안내도 다시 나오지 않았습니다.
- [ ] 다시 켭니다(전원을 뺐다가 다시 꽂습니다). 이번에는 두 버튼을 누르고 있다가 **약 2초 뒤 하나를 뗍니다**.
      아무 일도 일어나지 않습니다(끄기가 취소되고, SOS도 없습니다).

### G4. 전방 LiDAR 구간 (손이나 책으로 시험)

전방 빔은 폭이 좁습니다(2°). 2 m 거리에서 폭이 약 7 cm입니다. 목표물을 포드 정면,
머리 높이에 둡니다. 손보다 책이나 판자가 빔에 잘 맞습니다.

- [ ] 목표물이 약 **1.8 m**: 이마에 느리고 부드러운 진동(`zone3`). 음성은 없습니다.
- [ ] 목표물이 약 **1.0 m**: 빠른 진동(`zone2`)과 "앞에 장애물."
- [ ] 목표물이 약 **0.4 m**: 끊이지 않는 강한 진동(`zone1`)과 "멈추세요."
- [ ] 목표물을 약 **10 cm**까지 가져옵니다(센서가 잴 수 있는 거리보다 가깝습니다). `zone1` 진동이
      약 0.5초 동안 이어지다가 멈춥니다.
- [ ] 목표물을 멀리 치웁니다. 진동이 멈춥니다.

### G5. 책상 모서리로 내려가는 턱 시험

아래를 보는 LiDAR는 바닥까지의 거리를 학습한 값과 비교합니다. 안전을 위해 **더 먼 거리는 스스로 학습하지 않으며**,
**더 가까운** 거리가 안정적으로 유지될 때만 10초 뒤에 다시 학습합니다.

1. 도우미가 헬멧을 수평으로 **책상 윗면에서 약 1 m 위**에 들어, 아래쪽 빔이 헬멧보다
   약 80 cm 앞의 책상에 닿게 합니다. 처음에 "앞에 올라가는 턱." 경고가 나오는 것은 정상입니다.
   책상이 기본 바닥 거리보다 가깝기 때문입니다.
2. 더 가까운 책상 거리를 학습하도록 **적어도 12초 동안** 가만히 들고 있습니다.
3. 빔이 닿는 점이 책상 모서리를 넘어 바닥에 떨어지도록 헬멧을 천천히 앞으로 옮깁니다.
- [ ] **drop 패턴:** 모터 3개 모두 길게 두 번 떨리고, "앞에 내려가는 턱." 또는 "앞에 추락 위험."이라고 말합니다.
- [ ] 3초(재경고 대기 시간)를 기다린 뒤 책상 위로 되돌아오고, 높이 약 40 cm 상자를 빔 아래로 밀어 넣습니다.
      이마에 짧은 진동 세 번과 "앞에 올라가는 턱."이 나옵니다.

### G6. 카메라를 가려 고장 확인

1. 보통 밝기의 방에서 불투명한 캡이나 테이프로 카메라 렌즈를 완전히 가립니다.
- [ ] **4초** 안에 고장(FAULT) 패턴(이마에 아주 빠른 진동 세 번), "카메라가 가려졌거나 너무 어둡습니다.",
      "거리 센서는 계속 작동합니다."가 나옵니다.
- [ ] 가린 상태 그대로 1.0 m에서 G4를 반복합니다. LiDAR 경고는 계속 작동합니다.
- [ ] 고장 패턴이 10초마다 반복됩니다.
2. 렌즈를 다시 엽니다.
- [ ] "카메라 시야 복구됨."이라는 음성이 나옵니다. 고장 패턴이 멈춥니다.

### G7. 휴대폰 앱과 설정 변경 확인 안내

- [ ] 앱이 새 페어링 대화상자 없이 `OWSH-XXXX`에 연결됩니다(F에서 이미 등록했습니다).
- [ ] 앱에 상태(가동 시간, 온도, 고장)가 표시됩니다.
- [ ] 세모(△) B2 길게 누르기: 헬멧이 휴대폰에서 받은 위치를 말합니다.
- [ ] 앱 기록에 헬멧이 말한 내용이 나옵니다.
- [ ] 앱에서 헬멧 음성 안내를 끕니다. 헬멧이 "휴대폰에서 음성 안내를 껐습니다. 위험 경고는 계속 말합니다."라고 말합니다.
      다시 켭니다.
- [ ] 앱에서 낙차 감지 민감도를 낮춤으로 바꿉니다: "휴대폰에서 낙차 감지 민감도를 낮춤으로 바꿨습니다." 다시 보통으로 되돌립니다.
- [ ] 음량을 20 %로 바꿉니다: "휴대폰에서 음량을 20퍼센트로 바꿨습니다." 다시 되돌립니다.

### G8. 전원과 온도

- [ ] 평소 쓰는 보조배터리로 10분 동안 사용하는 사이에 "전원이 부족합니다. 곧 배터리를 충전하세요." 안내가 나오지 않습니다.
      나온다면 보조배터리나 케이블이 5 V 3 A를 공급하지 못하는 것입니다. 걷기 전에 교체하십시오.
- [ ] 선택: 경고가 작동하는지 확인합니다. 헬멧이 켜진 상태에서 1분 동안 약한 USB 전원(예: 5 V 1 A 충전기)으로
      전원을 공급하면서 세모(△) B2를 몇 번 누릅니다. 전압 부족이 약 10초 이어지면
      "전원이 부족합니다. 곧 배터리를 충전하세요."가 들리고, 앱 상태에 전압 부족이 표시되어야 합니다. 다시 제대로 된
      보조배터리로 바꿉니다.
- [ ] 뚜껑을 닫고 15분 동안 작동시킨 뒤, 실온 환경에서 앱에 표시되는 CPU 온도가 80 °C 미만이고,
      "헬멧이 과열되었습니다."라는 안내가 나오지 않았습니다.

하나라도 실패하면 밖에 나가기 전에 고치십시오. 흔한 원인은
[배선 가이드](02-배선가이드.md)의 8절 "자주 하는 실수"에 정리되어 있습니다.

## H. 보정

**실제 사용자가 헬멧을 쓴 상태에서**, 평소 걷는 자세로 보정합니다. 고개를 조금 숙이고 걷는 사람이 많은데,
그러면 센서가 보는 방향이 달라집니다.

### 설정 파일 위치

모든 임계값은 `firmware/config/default.yaml`에 있습니다. `owsh` 서비스는 이 파일로 펌웨어를 시작합니다
(`/etc/systemd/system/owsh.service` 참고). 개인 설정이 업데이트로 덮어써지지 않게 하려면, 이 파일을 복사하고(예:
`config/my.yaml`), 서비스 파일의 `--config`를 복사본으로 바꾼 다음
`sudo systemctl daemon-reload && sudo systemctl restart owsh`를 실행합니다. `setup_pi.sh`를 다시 실행하면
서비스 파일이 새로 쓰이므로, 그 뒤에는 이 단계를 반복하십시오.

### H1. 전방 LiDAR 방향

1. 사용자가 평평한 벽을 마주 보고 평소 자세로 **1.5 m** 떨어져 섭니다(이마에서 잽니다).
2. 기대 결과: `zone3` 느린 진동. 1.0 m에서 `zone2`. 0.5 m에서 `zone1`.
3. 구간이 너무 일찍 나오거나, 늦게 나오거나, 아예 나오지 않으면 빔이 위나 아래를 향하고 있을 가능성이 큽니다.
   2 m 거리에서 5° 기울면 빔이 닿는 점이 약 17 cm 움직입니다. `mount_pitch_deg`와 새들 위에 포드가 앉은 상태를 확인합니다.
4. 구간 거리는 설정값입니다(설계서 §5.1). 충분한 이유가 있을 때만 바꾸고, 그 이유를 기록하십시오.

### H2. 아래쪽 LiDAR 기울기와 높이

1. 사용자가 평소 자세로 헬멧을 쓴 상태에서, 도우미가 휴대폰 경사계를 포드의
   아래쪽 LiDAR 면에 댑니다.
2. 설계값은 **수평에서 아래로 50°**입니다. 다른 각도가 측정되면
   `dropoff.tilt_deg`를 측정값으로 설정합니다.
3. 착용했을 때 포드가 바닥에서 얼마나 높은지 재서 `dropoff.sensor_height_m`에 설정합니다
   (기본값 1.7 m). 펌웨어는 이 값에서 시작합니다. **더 먼 바닥 거리는 자동으로 학습하지 않으므로**
   (설계서 §5.2 안전 규칙), 처음 높이를 정확히 넣는 것이 중요합니다. 키가 큰 사용자라면 더욱 그렇습니다.
4. **앞을 볼 수 있는 도우미가 사용자의 팔을 잡은 상태로**, 위치를 알고 있는 연석이나 계단 맨 윗부분을 향해
   천천히 걸어갑니다. 가장자리에 닿기 전에 drop 경고가 나와야 합니다.

### H3. 낙차 감지 민감도

- 기본값: 반사 신호가 돌아오지 않는 경우(예: 아주 어둡거나 젖은 바닥)는 DROP으로 처리합니다. 낙차를 놓치는 것이
  잘못된 경고보다 더 나쁘기 때문입니다.
- 어두운 바닥에서 잘못된 drop 경고가 너무 잦다면, 휴대폰 앱에서 낙차 감지 민감도를
  `low`로 바꾸거나 설정 파일에서 `dropoff.no_return_is_drop: false`로 할 수 있습니다. 민감도를 낮추면 헬멧은 언제나
  음성으로 알려 줍니다. **바꾸기 전에 이 선택의 장단점을 사용자와 보행지도사(O&M 전문가)에게 설명하십시오.**

### H4. 카메라 시야

서비스를 멈춘 상태에서 사진을 찍습니다: `rpicam-still -o view.jpg`. 3 m 앞에 선 사람이
사진에 온전히 들어오고, 바닥이 대략 아래쪽 3분의 1을 채워야 합니다. 그렇지 않으면 포드 각도를 확인합니다.

### H5. 진동과 음성

- 패드마다 또렷하게 느껴져야 합니다. 그렇지 않으면 패드를 옮깁니다. **`haptics.max_duty`를 75 % 넘게 올리지 마십시오.**
  모터는 3 V 부품입니다.
- 음성 크기와 언어는 휴대폰 앱에서 설정합니다. 음성은 거리 소음 속에서도 또렷해야 하지만
  차 소리를 가려서는 안 됩니다.
- [05 · 사용자 가이드](05-사용자가이드.md)와 시뮬레이터로 사용자에게 진동 패턴을 알려 줍니다.

### H6. 휴대폰 앱, 긴급 전화번호, 보호자

앱에서 **나라별 긴급 전화번호**를 고릅니다(예: 한국은 119(구급·화재)나 112(경찰), 다른 나라는 112나 911 등).
보호자 전화번호를 추가하고, 시험이라는 것을 미리 알고 있는 보호자에게 SMS 보내기를 시험합니다.

### H7. 얼굴 등록(선택)

등록에 **동의한** 사람만 등록하십시오. 카메라가 사용 중이므로 먼저 서비스를 멈춘 다음, `firmware` 폴더에서
실행합니다.

```bash
sudo systemctl stop owsh
.venv/bin/python -m owsh.tools.enroll_face --name "Mina" --tag friend --camera 0
sudo systemctl start owsh
```

사용자가 경고받고 싶은 사람은 `--tag avoid`로 등록합니다. 사진과 얼굴 데이터는 헬멧 안에만
저장됩니다(설계서 §5.4). 등록된 사람을 확인하려면 `--list`를, 지우려면 `--remove "Mina"`를 붙여 실행합니다.

## I. 첫 실제 보행 전에

1. [07 · 시험계획](07-시험계획.md)의 절차를 실행합니다. 적어도 T2, T4, T5, T8, T9, T13, T14는 해야 합니다.
2. 처음 몇 번의 실외 보행은 **평소처럼 흰지팡이나 안내견과 함께** 하고, 보행지도사(O&M 전문가)나
   믿을 수 있는 앞을 볼 수 있는 동행자가 옆에서 함께 걷습니다.
3. 익숙하고 조용한 곳에서 시작합니다. 천천히 범위를 넓혀 갑니다.
4. 잘된 점과 잘 안된 점을 [현장 시험 보고서](../../.github/ISSUE_TEMPLATE/field_test_report.yml)에 기록합니다.

## 전원 끄기와 메모리 카드 관리

- **안전하게 끄기로 전원을 끕니다:** 원(○) B1과 네모(□) B3를 함께 5초 동안 누르고 있습니다. LED가 꺼질 때까지 기다린 다음
  전원을 뺍니다.
- 정상 종료 없이 전원을 끊으면 드물게 microSD 카드가 손상될 수 있습니다. 사용자에게 안전하게 끄는 방법을 알려 주십시오.
- 좋은 A2 등급 카드를 쓰고, 작동하는 카드의 **백업 이미지를 보관하십시오**(예: Raspberry Pi
  Imager나 `dd` 사용). 그러면 몇 분 안에 헬멧을 복구할 수 있습니다.
- M.2 HAT에 연결한 NVMe 드라이브가 microSD보다 튼튼합니다.

다음: [05 · 사용자 가이드](05-사용자가이드.md)

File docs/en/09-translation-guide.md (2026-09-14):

# 09 · Translation Guide

> Part of the Open Walking Safety Helmet · Licensed CC BY 4.0 · © 2026 CLSOFTLAB, Dr. Lee Il-guk

The helmet speaks to people in the middle of a street. A translation here is safety equipment.
A warning that is slow to say, easy to mishear or ambiguous can hurt someone. This guide explains how
to add a language carefully, and how it becomes **verified**.

## Contents

1. [What can be translated](#1-what-can-be-translated)
2. [The "verified" rule](#2-the-verified-rule)
3. [Adding a voice language (helmet)](#3-adding-a-voice-language-helmet)
4. [Adding an app language](#4-adding-an-app-language)
5. [Writing good safety phrases](#5-writing-good-safety-phrases)
6. [Glossary of safety terms](#6-glossary-of-safety-terms)
7. [Review checklist for verification](#7-review-checklist-for-verification)
8. [Translating the documentation](#8-translating-the-documentation)
9. [Language status](#9-language-status)

## 1. What can be translated

| What | File | Used for |
|---|---|---|
| Helmet voice messages | `firmware/owsh/i18n/<lang>.json` | Everything the helmet says (spec §7.1) |
| Phone app interface | `app/i18n/<lang>.json` | Buttons, labels, screen reader text, SOS screen, SMS text |
| Sign danger keywords | `ocr.danger_keywords.<lang>` in `firmware/config/default.yaml` | OCR adds "Warning sign:" when a sign contains these words (spec §5.5) |
| Documentation | `docs/<lang>/` | Guides like this one |

`<lang>` is a language code, for example `es`, `fr`, `pt`, `ar`, `hi`, `zh-CN`, `ja`, `sw`.
Use a region suffix only when the difference matters for safety or clarity (for example `pt-BR`, `zh-TW`).

Reference files: [`firmware/owsh/i18n/en.json`](../../firmware/owsh/i18n/en.json),
[`firmware/owsh/i18n/ko.json`](../../firmware/owsh/i18n/ko.json), and the app files in [`app/i18n/`](../../app/i18n/).

## 2. The "verified" rule

From the spec's global project rules:

- `en` and `ko` are maintained by the core team.
- Any other language is welcome, but it is marked **verified** only after review by **a native speaker who is
  blind, or an O&M instructor** who is a native speaker.
- **Unverified languages still ship,** with a first-boot notice telling the user the language has not been
  verified yet.

Why this rule? Sighted translators often write phrases that read well but sound unclear when heard once, in
traffic, through a bone-conduction headset. People who rely on speech every day, and people who teach
independent travel, catch those problems.

How verification happens:

1. The translator opens a pull request with the language files.
2. A reviewer who meets the rule reviews the **voice phrases** with the checklist in
   [section 7](#7-review-checklist-for-verification), ideally by listening to them through the helmet or the simulator.
3. The reviewer comments on the pull request: which role they have (blind native speaker or O&M instructor),
   that they listened to the phrases, and what they changed. They may stay anonymous publicly; maintainers may
   confirm privately.
4. A maintainer adds the language code to `VERIFIED_LANGS` in `firmware/owsh/i18n/__init__.py` (this switches off
   the first-boot notice) and updates the [language status table](#9-language-status).
5. Any later change to a safety phrase (level P0–P2) needs a new review for that phrase.

## 3. Adding a voice language (helmet)

1. **Open an issue** with the [translation form](../../.github/ISSUE_TEMPLATE/translation.yml), so others know
   you are working on it.
2. **Copy** `firmware/owsh/i18n/en.json` to `firmware/owsh/i18n/<lang>.json`.
3. **Translate only the values.** Keep every key exactly as it is.
4. **Keep `{placeholders}` unchanged**, for example `{name}`, `{what}` or `{count}`. You may move them within the sentence.
5. **Keep every key.** The firmware tests check that each language file has exactly the same keys and
   `{placeholders}` as `en.json`. If you cannot translate a phrase yet, leave the English text as the value and list
   it in the pull request. (At run time a missing phrase falls back to English, so it never silences a warning, but
   the tests will still fail.)
6. **Check the speech engine.** The default engine on the Pi is `espeak-ng`. Check your language exists:
   ```bash
   espeak-ng --voices | grep -i <lang>
   espeak-ng -v <lang> "your translated warning"
   ```
   If `espeak-ng` pronounces it badly, note it in the pull request. A `piper` voice may be better (spec §7.1).
7. **Add danger keywords** for sign reading under `ocr.danger_keywords` in `firmware/config/default.yaml`, as a new
   `<lang>:` list (for example the words for "danger", "caution", "wet floor", "construction"). Text reading in a new
   script may also need a recognition model for that script (`ocr.rec_model_path`) and an entry in `ocr.languages`.
8. **Listen in the simulator** on a PC, with your language selected:
   ```bash
   python -m owsh --sim --lang <lang>
   ```
   Press the simulated buttons and move the LiDAR sliders so each warning is spoken.
9. **Validate the JSON** and run the tests (they check key and placeholder parity):
   ```bash
   python -m json.tool firmware/owsh/i18n/<lang>.json > /dev/null
   cd firmware && python -m pytest -q
   ```
10. **Open a pull request.** Say whether a reviewer who meets the verified rule is available.

Format rules:

- UTF-8, no byte-order mark, 2-space indentation, no trailing commas.
- Keep the same key order as `en.json` so diffs are easy to review.
- Numbers and units: the firmware inserts numbers. Write units the way they are spoken
  ("metres", not "m"). Metric is the default; imperial is selectable for voice.
- Plurals: object names have two keys, `.one` and `.many` (for example `class.person.one` and
  `class.person.many` with `{count}`). If your language needs more forms, choose a phrasing that works for any
  number, and mention it in the pull request.

Example entries from `en.json`:

```json
{
  "obstacle.stop": "Stop.",
  "obstacle.ahead": "Obstacle ahead.",
  "approach.p2.right": "{what} approaching from the right.",
  "class.person.many": "{count} people",
  "face.friend.left": "{name} is ahead on the left."
}
```

## 4. Adding an app language

1. Copy `app/i18n/en.json` to `app/i18n/<lang>.json`.
2. Translate values; keep every key and `{placeholder}` (the app tests check this too).
3. Add the language code to `SUPPORTED_LANGUAGES` in `app/js/i18n.js`.
4. **Screen reader text matters as much as visible text.** Labels for buttons and status must make sense when read alone.
5. **The SOS screen and the SMS text are safety text.** The SMS goes to guardians and may be read by emergency
   services. Keep it short and clear: who needs help, that it is an emergency, and the map link.
6. **Emergency numbers are never translated into the text.** They are a per-country setting. Do not write
   "call 112" or "call 911" into a string.
7. For right-to-left languages (for example `ar`), check that the layout is mirrored and the screen reader reads in the right order.
8. Run the app tests with Node 22 (`cd app && node --test tests/*.test.mjs`), then open the app on a phone with the screen reader on (TalkBack or VoiceOver) and
   go through every screen.

## 5. Writing good safety phrases

Priority P0–P2 messages (spec §6.1) are the most important. When writing them:

- **Short.** A warning must finish before the hazard arrives. Aim for one to three words. "Stop" must be as short
  as your language allows.
- **Action first** when the phrase asks for action. Use a direct imperative. Avoid polite forms that add syllables
  or sound optional, unless the direct form is offensive in your culture.
- **Hard to mishear.** "Step up" and "Step down" must sound clearly different, not just by one short syllable.
  If they are too similar, change the wording (for example "Step down" versus "Kerb up").
- **Left and right** are always from the wearer's point of view.
- **One word, one meaning.** Use the same word for the same thing everywhere. Do not switch between synonyms.
- **No jokes, no idioms, no regional slang** in warnings.
- **Test in noise.** Listen to the phrase with street noise playing, through an open-ear headset, at a normal volume.
- **Keep the message ids' meaning.** Do not merge two messages into one, or change what a message warns about.

## 6. Glossary of safety terms

Translate these consistently, in both the helmet and the app. The Korean column shows the reference translation
used by the core team.

| Term (English) | Meaning and notes | Korean reference |
|---|---|---|
| Stop | Stop walking now. Shortest possible form. Spoken for Z1 obstacles. | 멈추세요 |
| Obstacle ahead | Something at head height 0.6–1.2 m ahead. | 앞에 장애물 |
| Step down ahead | A step, kerb or stairs going down. | 앞에 내려가는 턱 |
| Drop ahead | A deeper drop: platform edge, stairs, hole. | 앞에 추락 위험 |
| Step up ahead | A step up or a low obstacle. Must sound clearly different from "step down". | 앞에 올라가는 턱 |
| approaching | Moving toward the wearer. Used with an object and a side. | 접근 |
| left / right | From the wearer's point of view. | 왼쪽 / 오른쪽 |
| ahead | In front of the wearer. | 앞 |
| person, bicycle, car, motorcycle, bus, truck, dog | Detector classes that can approach. Use everyday words. | 사람, 자전거, 자동차, 오토바이, 버스, 트럭, 개 |
| Warning sign: | Prefix before reading a sign with danger words. | 경고 표지: |
| Emergency alert | The SOS function. Must not be confused with a normal notification. | 긴급 신고 |
| Emergency alert in 10 seconds. Press any button to cancel. | SOS countdown. | 10초 뒤 긴급 신고를 보냅니다. 취소하려면 아무 버튼이나 누르세요. |
| Sending emergency alert to the phone. | The helmet is still trying to reach the phone. Must not sound like "sent". | 휴대폰으로 긴급 신고를 보내는 중입니다. |
| Emergency alert sent | Spoken only after the phone confirmed it received the alert. | 긴급 신고를 보냈습니다 |
| cancel / cancelled | Stop the SOS countdown. | 취소 / 긴급 신고를 취소했습니다 |
| Phone not connected | The helmet cannot reach the phone. | 휴대폰이 연결되지 않았습니다 |
| fault | A part of the helmet stopped working. Do not soften it to "problem" or "issue" if that sounds minor. | 고장 |
| Camera is covered or too dark | Camera blocked fault. | 카메라가 가려졌거나 너무 어둡습니다 |
| Distance sensors still active | LiDAR warnings still work. | 거리 센서는 계속 작동합니다 |
| recovered | A failed part works again. | 복구됨 |
| muted / unmuted | Low-priority speech off / on. Warnings and answers to button presses are still spoken. | 음성 안내를 끕니다 / 음성 안내를 켭니다 |
| Shutting down. | Safe shutdown started (B1 + B3 held 5 s). | 전원을 끕니다. |
| Power is low. Charge the battery soon. | Under-voltage warning. The helmet may stop soon. | 전원이 부족합니다. 곧 배터리를 충전하세요. |
| Helmet is overheating. | CPU too hot; warnings from the camera may be slower. | 헬멧이 과열되었습니다. |
| Voice info muted by phone. Warnings are still spoken. | Safety-reducing change made from the phone; always spoken. | 휴대폰에서 음성 안내를 껐습니다. 위험 경고는 계속 말합니다. |
| Drop-off sensitivity set to low by phone. | Safety-reducing change made from the phone; always spoken. | 휴대폰에서 낙차 감지 민감도를 낮춤으로 바꿨습니다. |
| Volume set to {volume} percent by phone. | Volume below 30 % set from the phone; always spoken. | 휴대폰에서 음량을 {volume}퍼센트로 바꿨습니다. |
| New phone paired: {name}. | A phone was paired. If the user did not do it, it is a security warning. | 새 휴대폰이 등록되었습니다: {name}. |
| friend | An enrolled person the wearer wants to know about. | 지인 |
| person to avoid | An enrolled person the wearer wants a warning about. Neutral wording, not insulting. | 피하고 싶은 사람 |
| Text reading is not installed | OCR not available. | 문자 읽기 기능이 설치되어 있지 않습니다 |
| Where am I | Location request. | 여기가 어디예요 / 현재 위치 |
| metre(s) | Distance unit, spoken form. | 미터 |
| Call emergency number | App button. The number itself comes from settings. | 긴급 전화 걸기 |
| Send SMS to guardians | App button. | 보호자에게 문자 보내기 |
| guardian | A trusted contact who receives SOS messages. | 보호자 |

## 7. Review checklist for verification

The reviewer (a native speaker who is blind, or an O&M instructor) checks each P0–P2 phrase:

- [ ] I listened to it through the helmet or the simulator, not only read it.
- [ ] I understood it the first time, with street noise in the background.
- [ ] It is short enough to act on while walking.
- [ ] It tells me what to do or what is there, without ambiguity.
- [ ] "Step up" and "step down" (or equivalents) cannot be confused.
- [ ] Left and right are from my point of view.
- [ ] The same thing is called the same way in every message.
- [ ] The tone is right: urgent where needed, never alarming for information messages.
- [ ] The speech engine pronounces it correctly.
- [ ] The first-boot message clearly says the helmet assists and does not replace the cane or guide dog.

For the app:

- [ ] Every screen works with the screen reader.
- [ ] The SOS screen and SMS text are clear to a stranger reading them.

## 8. Translating the documentation

- Documentation translations are welcome under `docs/<lang>/`. Start with the user guide and safety pages, because
  they matter most to users.
- Keep the licence line at the top of each page, translated.
- Keep every number, pin, command and file name unchanged.
- Write natural text for your readers, not a word-by-word translation.
- Add your language to [`docs/README.md`](../README.md).

## 9. Language status

| Code | Language | Voice (helmet) | App | Status |
|---|---|---|---|---|
| `en` | English | core team | core team | Maintained by the core team; listed in `VERIFIED_LANGS`. Further review by blind native speakers is welcome. |
| `ko` | 한국어 (Korean) | core team | core team | Maintained by the core team; listed in `VERIFIED_LANGS`. Further review by blind native speakers is welcome. |
| other | — | — | — | Not yet available. [Open a translation issue.](../../.github/ISSUE_TEMPLATE/translation.yml) |

When a language is verified, the maintainer adds the reviewer role and date here.

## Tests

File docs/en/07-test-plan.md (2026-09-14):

# 07 · Test Plan

> Part of the Open Walking Safety Helmet · Licensed CC BY 4.0 · © 2026 CLSOFTLAB, Dr. Lee Il-guk

This plan expands the verification summary in [spec §11](00-system-design-spec.md#11-verification-plan-summary)
into step-by-step procedures. Each test has an ID (T1–T12), setup, steps, pass criteria and what to record.
The pass criteria come from the spec. Where this plan adds detail (trial counts, tolerances, safety
precautions), it says so. T13–T15 are **proposed additions** for features added to the spec after §11 was
written (safe shutdown, Bluetooth security, power warnings); they are not yet part of spec §11.

Read [06 · Safety](06-safety.md) first. **Never test with real traffic or real dangerous drops.**

## Contents

1. [General rules](#1-general-rules)
2. [Record the build under test](#2-record-the-build-under-test)
3. [Summary](#3-summary)
4. [Procedures T1–T15](#4-procedures-t1t15)
5. [Results table template](#5-results-table-template)
6. [Per-trial log template](#6-per-trial-log-template)
7. [Field test report template](#7-field-test-report-template)

## 1. General rules

- **Safety first.** A sighted spotter accompanies every walking test. Use soft mock obstacles. Stop
  immediately if anyone feels unsafe.
- **Record everything,** including failures and odd behaviour. A failed test with good notes is valuable.
- **Use the helmet log and the phone app log** as the primary timing source. Every alert of level P3 or
  higher is sent to the phone as an `alert` message with a timestamp `ts` (spec §8.1). Keep the
  service log too: `journalctl -u owsh -o short-precise`.
- **Video helps.** A phone filming at 60 fps or more, with floor marks in view, lets you check distances
  and timing afterwards. Get consent before filming people.
- **One change at a time.** If you change configuration between trials, record it and restart the count.
- **Tolerances.** Measure distances with a tape measure to ±2 cm. Mark floor positions with tape.

## 2. Record the build under test

Fill this in once per test session.

```
Date / place:
Tester(s) and roles:
Firmware commit (git rev-parse --short HEAD):
Config file used and differences from default.yaml:
Raspberry Pi model / RAM:           OS image (Bookworm date):
Camera: Camera Module 3 Wide        LiDAR: TF-Luna ×2 (FWD 0x10, DOWN 0x11)
Helmet make / model / size:         Added mass (g):
Measured down-LiDAR tilt (deg):     Pod height above ground when worn (m):
Power bank model / capacity:
Weather / light / temperature:
```

## 3. Summary

| ID | Test | Pass criterion (spec §11) |
|---|---|---|
| T1 | Unit tests `pytest` | all pass |
| T2 | Reflex latency LiDAR → motor | ≤ 60 ms (log timestamp) |
| T3 | Vision FPS on Pi 5 | ≥ 8 FPS NanoDet 416 |
| T4 | Head-height obstacle (branch mock at 1.8 m) | Z2 before 1.2 m, Z1 before 0.6 m, 20/20 trials |
| T5 | Stairs down (5 staircases, day/night) | DROP before first step edge 19/20 |
| T6 | Approaching bicycle / person | APPROACH alert with TTC ≥ 1.5 s, 18/20 |
| T7 | False alarm rate, 30 min city walk | ≤ 2 P1 false alarms / 10 min |
| T8 | Fault injection: unplug camera / LiDAR; cover the lens | FAULT within 3 s for unplug (2 s frame timeout), within 4 s for covered lens, within 1 s for LiDAR |
| T9 | SOS: hold B3, fall on mattress | countdown, phone receives `sos` |
| T10 | Battery 20 000 mAh continuous | ≥ 6 h |
| T11 | Impact: added modules detach / do not penetrate | visual check after 1 m drop of helmet on headform; never certification-test a modified helmet for sale without an accredited lab |
| T12 | User trials with blind walkers + O&M instructor | qualitative report, safety incidents = 0 |

Proposed additions (this plan, not yet in spec §11):

| ID | Test | Pass criterion (this plan) |
|---|---|---|
| T13 | Safe shutdown: hold B1 + B3 for 5 s | 10/10 clean shutdowns, 10/10 aborts without side effects, no SOS triggered |
| T14 | Bluetooth: non-paired device rejected, safety changes confirmed | no effect from a non-paired device; spoken confirmations, `say` cap and rate limit as spec §8.3 |
| T15 | Power and temperature warnings | under-voltage warning after ≥ 10 s, not repeated within 5 min; overheating warning at ≥ 80 °C |

Recommended order: T1 → T8 → T13 → T14 → T15 → T2 → T3 → T9 → T4 → T5 → T6 → T10 → T7 → T11 (on a separate
helmet) → T12.

## 4. Procedures T1–T15

### T1 · Unit tests

**Purpose.** The pure logic (arbiter, reflex zones, drop-off, tracker/TTC, haptic mixer, protocol,
buttons, fall detection) behaves as specified.

**Setup.** Any PC (Linux, macOS, Windows) with Python 3.11 or 3.12, and the Raspberry Pi itself.

**Steps.**

1. On a PC, from the repository root:
   ```bash
   pip install -e "firmware[dev]"
   cd firmware && python -m pytest -q
   ```
2. On the Raspberry Pi, from the `firmware` folder: `.venv/bin/python -m pytest -q`.
3. For app changes, also run (Node 22): `cd app && node --test tests/*.test.mjs`.

**Pass.** All tests pass on both machines. No skipped safety tests without a written reason.

**Record.** Commit, Python version, number of tests passed, any skips.

---

### T2 · Reflex latency, LiDAR → motor

**Purpose.** The head-height reflex path reacts fast enough (spec §5.1, P5).

**Setup.**

- Helmet running on the bench, forward LiDAR pointing at an empty space more than 3 m deep.
- A flat card (A4 cardboard) to swing into the beam at about 0.4 m.
- The firmware log records the latency directly: lines `reflex zone=… sample_ts=…` and
  `haptic_on … latency_ms=…`. Follow it with `journalctl -u owsh -f -o short-precise`.
- Optional cross-check: a phone filming at 240 fps showing both the card and a motor (a small paper
  flag taped to the pad makes vibration visible).

**Steps.**

1. Swing the card quickly into the beam at 0.4 m and hold it.
2. From the log, read `latency_ms` on the `haptic_on` line for `zone1`. It is measured from the LiDAR sample
   timestamp (`sample_ts`) to the motor output.
3. Cross-check a few trials against the video, if you filmed them.
4. Remove the card, wait 3 s, repeat. Do **20 trials**.

**Pass.** Latency ≤ 60 ms in **every** trial. (The spec gives ≤ 60 ms. This plan applies it to all
20 trials.)

**Record.** Each latency, median and maximum. Note that the 3-sample median filter adds up to one
sample period (20 ms at 50 Hz) by design.

---

### T3 · Vision frame rate on Pi 5

**Purpose.** The detector runs fast enough for approach warnings (spec §5.3).

**Setup.**

- Helmet fully assembled, lid closed, Active Cooler fitted, at room temperature (20–30 °C).
- Default detector NanoDet-Plus-m 416.
- The camera looks at a busy scene (a street through a window, or a walking video on a monitor).
- Phone app connected to read `status` messages (`fps`, `cpu_temp_c`), or the service log.

**Steps.**

1. Start the helmet. Wait 10 minutes to warm up.
2. Record `fps` and `cpu_temp_c` from 30 consecutive `status` messages (5 minutes).
3. Optional: repeat outdoors in direct sun, and record the result separately.

**Pass.** Average FPS ≥ 8 over the 5-minute window.

A detector-only benchmark on a recording is also available: `python -m owsh.tools.bench --video <file>`.
Record it separately; the pass criterion uses the running helmet.

**Record.** Min / mean / max FPS, CPU temperature, `throttled` and `undervoltage` from `status`.

---

### T4 · Head-height obstacle

**Purpose.** Hanging obstacles are warned about in time (spec §5.1).

**Setup.**

- Indoor hall or quiet outdoor area, level floor, at least 6 m of clear space.
- **Branch mock** hung from a stand: a foam pool noodle or a light cardboard board about 60 cm wide,
  lower edge **1.8 m** above the floor. Adjust to the tester's forward-LiDAR height (±5 cm) and record
  the actual heights.
- Floor tape marks at **1.2 m** and **0.6 m** from the obstacle (measured horizontally to the pod's front).
- A **sighted spotter** walks beside the tester, ready to stop them. Sighted testers may wear the helmet
  with eyes open for early trials; record who wore it.
- Phone app log running (alerts carry `dist_m`), and video from the side.

**Steps.**

1. The tester starts 4 m away, facing the obstacle.
2. The tester walks toward it at normal walking speed in natural head posture.
3. The spotter stops the tester at the first `zone1` continuous buzz, or before contact.
4. From video and log, check when `zone2` began and when `zone1` began relative to the floor marks.
5. Repeat for **20 trials**: 10 at normal speed, 10 at slow speed. Vary the obstacle: at least 5 trials
   with a real leafy branch and 5 with a flat sign board.

**Pass (all 20/20).**

- `zone2` begins **before** the pod passes the 1.2 m mark.
- `zone1` begins **before** the pod passes the 0.6 m mark.
- No contact with the obstacle.

**Record.** Per trial: speed, obstacle type, logged `dist_m` at Z2 and Z1 onset, video check, pass/fail.
Also note, **outside the pass count**, results with a thin rope or wire. These are a known limitation.

---

### T5 · Stairs down

**Purpose.** Downward drops are warned about before the edge (spec §5.2).

**Setup.**

- **5 different staircases** (for example concrete outdoor, tiled indoor, dark carpet, metal, a platform
  or kerb edge), each with a level approach of at least 5 m.
- Each staircase tested in **daylight** and at **night or in darkness** (lights off, or evening outdoors).
- Tape mark at the first step edge.
- **Safety:** the spotter holds the tester's arm on the stair side. The tester walks with the cane as usual.
  Stop at the warning; do not descend in the test.

**Steps.**

1. Start 5 m back on level ground. Walk at normal speed for at least 3 s so the ground distance is learned.
2. Walk toward the first step edge.
3. The spotter stops the tester at the `drop` warning, or at 0.5 m before the edge, whichever is first.
4. From video and log, check whether `drop` began before the leading foot reached the edge mark.
5. Do 2 trials per staircase per lighting condition: 5 × 2 × 2 = **20 trials**.

**Pass.** `drop` warning before the first step edge in **at least 19 of 20** trials.

**Record.** Staircase description, surface colour and material, lighting, distance from edge at warning,
false `drop` or `step_up` alarms during the approach (report them in T7 too).

---

### T6 · Approaching bicycle / person

**Purpose.** Moving objects heading for the user are warned about with enough time (spec §5.3).

**Setup.**

- A closed, empty area (empty car park, sports hall), **no traffic**.
- Tester stands still, facing forward, behind a marked line.
- **Approachers:** an experienced cyclist riding at about 10–12 km/h (≈ 3 m/s), and a person walking briskly
  (≈ 1.5 m/s). Both start 15 m away.
- Approach paths: straight ahead, from about 30° left, and from about 30° right.
- A **turn-off marker 2 m** before the tester. The approacher always turns aside there. Foam barrier in front
  of the tester for extra safety.
- Distance markers every 1 m along each path. Video from the side at ≥ 60 fps, synchronised with the app log.

**Steps.**

1. The approacher moves at a steady speed toward the tester along the path.
2. At the moment of the first `approach_*` alert (P1 or P2), read the approacher's position from the video.
3. TTC at alert = remaining distance to the tester ÷ approacher speed (measured from video between markers).
4. Do **20 trials**: 10 bicycle, 10 person, spread across the three directions.

**Pass.** An APPROACH alert with **TTC ≥ 1.5 s** in **at least 18 of 20** trials.

**Record.** Per trial: approacher type, direction, speed, TTC at alert, alert level, whether the reported
side (`left` / `center` / `right`) was correct (recorded, not part of the pass criterion), lighting.

---

### T7 · False alarm rate, city walk

**Purpose.** Warnings are trustworthy in real streets. Too many false alarms make users ignore warnings.

**Setup.**

- A 30-minute route with ordinary pavements, shop fronts, trees, parked cars, a crossing, and some people.
  Daylight, dry weather (repeat later in other conditions as extra data).
- The tester walks with cane or guide dog as usual. A sighted observer walks alongside.
- Chest or head-mounted video, and the app log of all `alert` messages with `level`.

**Steps.**

1. Walk the route at normal pace for 30 minutes.
2. The observer notes the time of any real hazard.
3. Afterwards, review every **P1** alert (`zone1`, `drop`, `approach` P1) against video. Classify each as
   **true** (a real hazard that matches the alert definition) or **false**.
4. Also count false P2 alerts (recorded, not part of the pass criterion).

**Pass.** P1 false alarms ≤ 2 per 10 minutes on average, meaning **≤ 6 in 30 minutes**.
Also report the worst single 10-minute window.

**Record.** Route description, counts of true and false P1 and P2 alerts by type, likely causes
(dark surface, glass, rain, glare …).

---

### T8 · Fault injection

**Purpose.** Failures are announced; silence never means "safe" (spec P4, §5.7).

> **Hardware care.** Do not unplug the camera ribbon while the Pi is powered. It can damage the camera or
> the Pi. Use the power-off method for the camera below. Dupont wires to a LiDAR can be pulled while running,
> but pull only the named wire, carefully.

**Setup.** Helmet on the bench, log visible with precise timestamps, a stopwatch or 60 fps video.
Before touching hardware you can rehearse in the simulator: keys `l` / `k` unplug the forward / down LiDAR,
`c` covers the camera.

**Steps.**

1. **Forward LiDAR:** while running, pull S1's **5 V** Dupont wire. Note the time. Wait for the FAULT
   pattern and voice. Reconnect; check the recovery message. 5 trials.
2. **Down LiDAR:** same with S2. 5 trials.
3. **Camera (power-off method):** power off, disconnect the camera ribbon at the camera end, power on. From
   the log, measure from the moment the camera thread starts to the camera FAULT. 3 trials.
4. **Camera covered:** while running in a lit room, cover the lens with an opaque cap. Time from covering to
   the FAULT. Check that "Distance sensors still active." is spoken and the forward LiDAR still warns. 3 trials.
5. **IMU (optional):** pull the GY-521 VCC wire while running. 3 trials.
6. Check the FAULT pattern repeats every 10 s while a safety-relevant fault lasts (camera, LiDARs, motors, IMU).
7. **Non-safety component (recorded):** start without the face models present (or with Bluetooth disabled).
   Expect a single spoken announcement, no repeating `fault` pattern.

**Pass (spec §11).**

- Camera unplugged: FAULT within **3 s** (the frame timeout is 2 s).
- Lens covered: FAULT within **4 s**.
- LiDAR unplugged: FAULT within **1 s**.
- In every trial.

**Record.** Each measured time, the voice message heard, and whether recovery was announced.

---

### T9 · SOS

**Purpose.** An emergency can be raised by button or by a fall, and reaches the phone (spec §5.6, §7.3).

**Setup.**

- Phone app connected. Emergency number and a guardian contact configured. **Tell the guardian this is a test.**
- For falls: the helmet (with modules) on a **headform or a padded dummy head**, dropped onto a **thick mattress**.
  Do not ask a person to fall.

**Steps.**

1. **Button:** hold □ B3 for 3 s.
   - Expect `sos_countdown` (all motors, 1 Hz) and the voice countdown message.
   - The app shows the countdown.
   - Wait 10 s. Expect "Sending emergency alert to the phone.", then the app alarm and location and the call and
     SMS buttons.
   - "Emergency alert sent." must be spoken **only after** the app's `ack`. Check in the log that the order is
     `sos` sent → `ack` received → "Emergency alert sent.", and that the helmet stops repeating `sos` after the ack.
   - Optional: block the ack (for example close the app right after the countdown). Expect `sos` repeated every 5 s
     and **no** "Emergency alert sent.".
2. **Cancel:** start again, press any button during the countdown. Expect cancellation on the helmet and in the app.
3. **Fall:** drop the dummy head with the helmet from about 1 m onto the mattress. Leave it still.
   - Expect the countdown to start within about 3 s of coming to rest, reason `fall`.
   - Let the alert be sent. Check the app.
4. **Not a fall:** put the helmet down firmly on a table, nod and shake it hard, sit down heavily while
   wearing it. Expect **no** countdown. Record any false trigger.
5. **No phone:** turn Bluetooth off on the phone. Hold B3 3 s and let it run. Expect "Phone not connected"
   every 10 s, the `sos_countdown` pattern continuing for 60 s, and a fast-blinking LED. Press any button: it stops.

Suggested counts (this plan): button 3/3, cancel 3/3, fall 5/5, not-a-fall 10 events, no-phone 1.

**Pass.** Countdown starts, and the phone receives `sos`, in every button and fall trial.

**Record.** Trial results, time from trigger to countdown, any false fall triggers, SMS content received.

---

### T10 · Battery life

**Purpose.** A day of use is possible with the recommended power bank (spec §4.2).

**Setup.**

- A fully charged **20 000 mAh** USB-C PD power bank, the breakaway cable, room temperature 20–25 °C.
- Helmet fully assembled, camera looking at a moving scene, phone app connected.

**Steps.**

1. Connect the power bank and note the start time.
2. Leave the helmet running. Every hour, press □ B3 short (status) and note the result.
3. Note the time the helmet stops.
4. Check for undervoltage during the run: `vcgencmd get_throttled` (via SSH).

**Pass.** Runs continuously for **≥ 6 hours**.

**Record.** Power bank make and model, run time, temperature, throttling, restarts.

---

### T11 · Impact: modules detach or do not penetrate

**Purpose.** The add-ons do not make an impact worse (spec P1, P2).

> **Important.** This is a **visual design check only.** It is **not** a certification test.
> **Never certification-test a modified helmet for sale without an accredited lab.**
> The helmet used for T11 must be **destroyed and never worn** afterwards.

**Setup.**

- A **separate** helmet of the same model, used only for this test.
- **Dummy modules** with the same shape, straps, saddles and Dual Lock, and similar mass (printed parts filled
  with weights), to avoid destroying electronics.
- A headform or firm foam head that fits the helmet.
- A flat, hard surface. Safety glasses for everyone nearby.

**Steps.**

1. Mount the dummy modules exactly as in the assembly guide.
2. Drop the helmet on the headform from **1 m** onto the surface, landing on:
   - front (front pod),
   - rear-top (main case),
   - right side (button module).
3. After each drop, inspect.

**Pass (visual, every drop).**

- No module or fragment has pushed into the shell or the foam liner.
- No sharp fragment is left pointing toward the head or face.
- Modules either detached or stayed attached without denting the shell locally.
- Straps did not cut into the shell.

**Record.** Photos before and after each drop, what detached, any marks on the shell or liner.

---

### T12 · User trials with blind walkers and an O&M instructor

**Purpose.** Learn whether the helmet is useful, understandable and safe for real users.

**Setup.**

- Participants who are blind or have low vision and are experienced cane or guide dog users.
  Suggested 3–5 people per site.
- A qualified **O&M instructor** present at all times.
- **Informed consent** in an accessible format (braille, large print, audio or screen-reader-friendly file).
  If done through a university or hospital, follow its ethics review process.
- Routes: indoor course with mock obstacles → quiet familiar outdoor route → busier route, in that order.
- Stopping rules agreed in advance. Participants may stop at any time without giving a reason.

**Steps.**

1. **Training (30–60 min):** patterns and buttons, using [05 · User guide](05-user-guide.md) and the simulator.
2. **Pattern recall check:** play each vibration pattern in random order; the participant names it. Record accuracy.
3. **Indoor course** with cane or dog as usual, helmet on.
4. **Outdoor routes,** instructor within arm's reach.
5. **SOS practice:** start and cancel.
6. **Interview:** usefulness of each feature, comfort (weight, heat, pads), trust, annoyance from false alarms,
   what should change.

**Pass.** A qualitative report is produced, and **safety incidents = 0**.

Definition used in this plan:

- **Safety incident:** any injury, fall, or contact with an obstacle that causes pain.
- **Near miss** (recorded, reviewed, not counted as an incident): the instructor had to intervene to prevent contact or a fall.

Any incident stops the trial for that participant and triggers a safety review ([GOVERNANCE.md](../../GOVERNANCE.md)).

**Record.** A [field test report](#7-field-test-report-template) per participant or session (anonymised).

---

### T13 · Safe shutdown (proposed, not yet in spec §11)

**Purpose.** The helmet can be switched off without damaging the memory card, and the shutdown gesture never
triggers an SOS or another action by mistake (spec §7.2).

**Setup.** Helmet running on the bench or worn, log visible. Phone app connected, to see any `sos` message.

**Steps.**

1. Press ○ B1 and □ B3 within about 1 s of each other and hold both for 5 s.
   - Expect "Shutting down.", the `ready` pattern reversed (R → C → L), and power-off about 3 s later (LED off).
   - The app must receive no `sos` message, and the last message must not be repeated.
2. Reconnect power and let it boot. It must start normally ("Helmet ready.", ready pattern).
3. Repeat steps 1–2 for **10 trials**.
4. **Abort:** hold both buttons, release B1 after about 2 s. Expect nothing: no shutdown, no SOS, no repeat.
   Repeat releasing B3 instead. 5 trials each.
5. **Start in the wrong order (recorded, not a pass criterion):** hold B3 first and add B1 after 2 s. Note what
   happens. The user guide tells users to press both within about 1 s.
6. In the simulator you can pre-check with key `z` (`python -m owsh --sim`); power-off is only logged there.

**Pass (this plan).** 10/10 clean shutdowns and reboots; 10/10 aborts with no side effects; zero SOS countdowns
started by the gesture.

**Record.** Trial results, time from press to power-off, any SOS or repeat triggered, boot problems.

---

### T14 · Bluetooth: only the paired phone is accepted (proposed, not yet in spec §11)

**Purpose.** Nearby devices cannot mute the helmet, lower its sensitivity or make it speak (spec §8.3).

**Setup.**

- Helmet with default settings (`ble.security: encrypt`, `ble.bonded_only: true`).
- **Phone A:** paired with the helmet, running the app.
- **Phone B:** never paired, running the app or a generic BLE tool that can write to the Nordic UART RX characteristic.
- Log visible (`journalctl -u owsh -f`).

**Steps.**

1. Boot the helmet and wait **more than 120 s** (pairing window closed).
2. From phone B, connect and send `cfg` with `muted: true`, then `dropoff_sensitivity: low`, then `say`.
   - Expect: pairing is refused or no bonding happens; nothing changes on the helmet; no confirmation is spoken;
     the log shows the messages dropped.
3. From phone A (paired), send `cfg` with `muted: true`.
   - Expect "Voice info muted by phone. Warnings are still spoken." spoken even though mute is being switched on.
4. From phone A, set drop-off sensitivity to low: expect "Drop-off sensitivity set to low by phone."
5. From phone A, set volume to 20: expect "Volume set to 20 percent by phone."
6. From phone A, send 5 `say` messages within 3 s. Expect only one to be spoken.
7. While `zone1` is active (target at 0.4 m), send `say` with `level: 0` from phone A. Expect it **not** to
   interrupt "Stop." (capped at P2).
8. **Pairing window:** restart the helmet; within 120 s pair phone B. Expect "New phone paired: <name>."
   Then remove phone B's pairing (`bluetoothctl remove <address>`).
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

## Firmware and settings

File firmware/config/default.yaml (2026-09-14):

# Open Walking Safety Helmet (OWSH) - default configuration
# Every value mirrors docs/en/00-system-design-spec.md (v1.0). Section numbers refer to that spec.
# Copy this file, edit the copy and start with:  python -m owsh --config my.yaml
# Units: metres (m), seconds (s). Unknown keys are ignored with a warning.

general:
  lang: en                  # voice language: en | ko (phrases in owsh/i18n/<lang>.json)
  units: metric             # metric | imperial (voice only)
  data_dir: data            # faces DB, TTS cache, state. Relative paths are relative to firmware/
  models_dir: models        # ONNX models (python -m owsh.tools.download_models)
  log_level: INFO

pins:                       # BCM GPIO numbers, spec §4.2 (authoritative)
  haptic_left: 17           # -> ULN2003 IN1 -> M1 left temple
  haptic_center: 27         # -> ULN2003 IN2 -> M2 forehead
  haptic_right: 22          # -> ULN2003 IN3 -> M3 right temple
  button_b1: 5              # circle, front, active-low with pull-up
  button_b2: 6              # triangle, middle
  button_b3: 26             # square, rear
  status_led: 16

i2c:
  bus: 1                    # I2C1 on GPIO2/3, 400 kHz
  tfluna_forward_addr: 0x10 # factory address
  tfluna_down_addr: 0x11    # changed once with: python -m owsh.tools.tfluna_addr --from 0x10 --to 0x11
  mpu6050_addr: 0x68

reflex:                     # §5.1 forward LiDAR, head-height obstacles
  rate_hz: 50.0
  median_window: 3          # median of last 3 samples
  min_strength: 100         # strength < 100 or distance = 0 counts as "no return"
  zone3_m: 2.0              # Z3 notice:    2.0 >= d > 1.2  -> zone3 pattern, no voice
  zone2_m: 1.2              # Z2 warning:   1.2 >= d > 0.6  -> zone2 pattern, "Obstacle ahead"
  zone1_m: 0.6              # Z1 imminent:  d <= 0.6        -> zone1 continuous, "Stop"
  hysteresis_m: 0.1         # leaving a zone needs d > threshold + 0.1 m
  z1_no_return_hold_s: 0.5  # below 0.2 m TF-Luna gives no return: keep Z1 for 0.5 s, don't go silent
  zone2_voice_cooldown_s: 5.0   # "Obstacle ahead" at most once per 5 s
  zone1_voice_cooldown_s: 3.0   # "Stop" repeat limit
  zone3_alert_cooldown_s: 5.0   # BLE alert rate limit for Z3 notices

dropoff:                    # §5.2 down-looking LiDAR, drop-offs and steps
  enabled: true
  tilt_deg: 50.0            # sensor tilt below horizontal
  sensor_height_m: 1.7      # start value before learning: d0 = height / sin(tilt)
  learn_window_s: 3.0       # rolling median window of low-variance samples
  learn_max_std_m: 0.05     # window std-dev must be below this to learn (level ground)
  d0_min_m: 1.2             # learned d0 is clamped to 1.2..3.5 m
  d0_max_m: 3.5
  drop_ratio: 1.30          # DROP if d > d0 * 1.30 (or no return), sustained
  step_ratio: 0.70          # STEP UP if d < d0 * 0.70, sustained
  big_drop_ratio: 1.6       # d > d0 * 1.6 or no return -> "Drop ahead" instead of "Step down ahead"
  sustain_s: 0.12           # condition must last >= 120 ms
  cooldown_s: 3.0           # per type
  no_return_is_drop: true   # a missed drop is worse than a false alarm
  sensitivity: normal       # low (1.45 / 0.55) | normal (ratios above) | high (1.20 / 0.80)
  relearn_shorter_after_s: 10.0  # a stable shorter distance (e.g. sitting) is re-learned after 10 s
  allow_relearn_longer: false    # never silently learn a LONGER distance (could hide a platform edge)
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

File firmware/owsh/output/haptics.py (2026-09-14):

"""Haptic pattern engine and mixer (spec §6).

* Patterns follow the authoritative table in spec §6.2.
* The mixer renders every active pattern and takes the **maximum** intensity per motor at each
  10 ms tick, so continuous reflex patterns and one-shot patterns coexist.
* ``haptics.max_duty`` (0.75) is applied in the backend, right before the PWM output, so no
  code path can overdrive the 3 V motors.
* Every motor off->on transition caused by a pattern that carries a ``source_ts`` is logged with
  the latency since that source sample (spec §11 T2).
"""

from __future__ import annotations

import itertools
import logging
import threading
from dataclasses import dataclass, field

from ..clock import Clock
from ..config import HapticsConfig, PinsConfig
from ..events import Level

log = logging.getLogger("owsh.haptics")

Intensity = tuple[float, float, float]  # left, center, right in 0..1
OFF: Intensity = (0.0, 0.0, 0.0)
MOTORS = ("L", "C", "R")


@dataclass(frozen=True)
class Segment:
    dur_s: float
    lcr: Intensity


@dataclass(frozen=True)
class Pattern:
    name: str
    segments: tuple[Segment, ...]
    loop: bool = False
    level: Level = Level.P4

    @property
    def duration_s(self) -> float:
        return sum(s.dur_s for s in self.segments)

    def value_at(self, t: float) -> Intensity | None:
        """Intensity at ``t`` seconds after start, or None when a one-shot has finished."""
        total = self.duration_s
        if t < 0:
            return OFF
        if total <= 0:
            return None
        if self.loop:
            t = t % total
        elif t >= total - 1e-9:
            return None
        acc = 0.0
        for seg in self.segments:
            acc += seg.dur_s
            if t < acc - 1e-9:
                return seg.lcr
        return self.segments[-1].lcr


def _side(side: str, x: float) -> Intensity:
    return {
        "left": (x, 0.0, 0.0),
        "center": (0.0, x, 0.0),
        "right": (0.0, 0.0, x),
        "all": (x, x, x),
    }[side]


def _pulses(n: int, on_ms: float, off_ms: float, lcr: Intensity) -> tuple[Segment, ...]:
    segs: list[Segment] = []
    for _ in range(n):
        segs.append(Segment(on_ms / 1000.0, lcr))
        segs.append(Segment(off_ms / 1000.0, OFF))
    return tuple(segs)


def make_pattern(pattern_id: str, *, level: Level | None = None, n: int = 1, repeats: int = 10) -> Pattern:
    """Build a pattern from the spec §6.2 table.

    ``pattern_id`` examples: ``tick``, ``zone2``, ``drop``, ``approach_left``,
    ``person_friend_right``, ``turn_left``, ``count`` (with ``n``), ``sos_countdown``, ``fault``.
    """
    pid = pattern_id
    if pid == "tick":
        return Pattern(pid, (Segment(0.040, _side("center", 0.60)),), level=Level.P4)
    if pid == "zone3":
        return Pattern(pid, _pulses(1, 60, 440, _side("center", 0.40)), loop=True, level=Level.P3)
    if pid == "zone2":
        return Pattern(pid, _pulses(1, 80, 120, _side("center", 0.70)), loop=True, level=Level.P2)
    if pid == "zone1":
        return Pattern(pid, (Segment(0.100, _side("center", 1.0)),), loop=True, level=Level.P1)
    if pid == "drop":
        return Pattern(pid, _pulses(2, 400, 150, _side("all", 1.0)), level=Level.P1)
    if pid == "step_up":
        return Pattern(pid, _pulses(3, 100, 100, _side("center", 0.80)), level=Level.P2)
    if pid.startswith("approach_"):
        side = pid.split("_", 1)[1]
        lvl = Level.P1 if level is None else level
        x = 1.0 if lvl <= Level.P1 else 0.70
        return Pattern(pid, _pulses(3, 150, 80, _side(side, x)), level=lvl)
    if pid.startswith("person_friend_"):
        side = pid.rsplit("_", 1)[1]
        return Pattern(pid, _pulses(2, 80, 120, _side(side, 0.60)), level=Level.P3)
    if pid.startswith("person_avoid_"):
        side = pid.rsplit("_", 1)[1]
        return Pattern(pid, _pulses(4, 60, 60, _side(side, 0.90)), level=Level.P2)
    if pid in ("turn_left", "turn_right"):
        side = pid.split("_", 1)[1]
        return Pattern(pid, _pulses(1, 250, 750, _side(side, 0.70)), loop=True, level=Level.P3)
    if pid == "count":
        n = max(1, min(10, int(n)))
        return Pattern(f"count_{n}", _pulses(n, 120, 280, _side("center", 0.70)), level=Level.P3)
    if pid == "sos_countdown":
        # 1 Hz, 200 ms @ 100 % on all motors; 10 repeats = 10 s (60 for the no-phone alarm)
        return Pattern(pid, _pulses(max(1, repeats), 200, 800, _side("all", 1.0)), level=Level.P0)
    if pid == "fault":
        return Pattern(pid, _pulses(3, 50, 50, _side("center", 1.0)), level=Level.P0)
    if pid == "ready":
        return Pattern(pid, (Segment(0.1, _side("left", 0.6)), Segment(0.1, _side("center", 0.6)),
                             Segment(0.1, _side("right", 0.6))), level=Level.P4)
    if pid == "ready_reverse":  # safe shutdown: ready pattern reversed R -> C -> L
        return Pattern(pid, (Segment(0.1, _side("right", 0.6)), Segment(0.1, _side("center", 0.6)),
                             Segment(0.1, _side("left", 0.6))), level=Level.P1)
    raise KeyError(f"unknown haptic pattern {pattern_id!r}")


# ------------------------------------------------------------------------------ mixer
@dataclass
class _Active:
    pattern: Pattern
    start: float
    source_ts: float | None
    logged: set[int] = field(default_factory=set)
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

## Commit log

2026-09-14 Open Walking Safety Helmet v1.0 reference design
    Open-source walking safety helmet for blind and low-vision people, based on
    Korean patent KR 10-2560496 by CLSOFTLAB, Dr. Lee Il-guk, released royalty-free.
    - docs: system design spec (en/ko), BOM, wiring, 3D printing, assembly,
    user guide, safety, test plan, patent mapping and roadmap, translation guide
    - firmware: Raspberry Pi 5 Python firmware with PC simulator
    (LiDAR reflex path, drop-off detection, NanoDet object detection and
    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
    [assembly_preview.scad, aux_pod_base.scad, aux_pod_base.stl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]
2026-09-14 Add verified buying guides with purchase links (ko/en)
    - docs/ko/10-구매가이드.md: Korean shop carts (DeviceMart, Eleparts,
    ICbanQ alternatives), prices and stock as of 2026-09-15, 7 common buying
    mistakes, cost estimate, unpacking checklist
    - docs/en/10-buying-guide.md: official pages + DigiKey / The Pi Hut /
    Adafruit / SparkFun / DFRobot / Seeed listings, reseller finder
    - docs/bom.csv: url_official, url_global, url_korea columns
    - Fix W3: Dupont splitters, not Qwiic/STEMMA hubs (3.3 V only, TF-Luna needs 5 V)
    - Fix A1: real mic input and headset plug matching (TRRS)
    - README: link buying guide, correct module height wording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
    [bom.csv]
